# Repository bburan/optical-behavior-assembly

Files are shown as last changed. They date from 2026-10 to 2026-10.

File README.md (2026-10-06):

# Optical behavior assembly: parametric lickometer poke

A parametric [OpenSCAD](https://openscad.org/) model of a dual-beam, optical-fiber
lickometer poke, with presets for mice, rats and ferrets.

> **Status:** not yet print-tested. Fits, clearances and the optical signal across the
> wider rat/ferret beam gaps still need to be checked on a real print.

## Attribution

This work is **derived from the optical-fiber lickometer by Silva et al. (2024)**,
developed at the Champalimaud Foundation:

> Silva A, Carriço P, Fernandes AB, Saraiva T, Oliveira-Maia AJ, Alves da Silva J (2024).
> High-Precision Optical Fiber-Based Lickometer. *eNeuro* 11(7):ENEURO.0189-24.2024.
> https://doi.org/10.1523/ENEURO.0189-24.2024

Original design files: https://github.com/fchampalimaud/optical-lickometer (see
[`CONTRIB_ORIGINAL`](CONTRIB_ORIGINAL)). Their design includes the 3D-printed poke
(`Lickometer_Dual_Detection_Optical_Fiber-1..6`, LED and photosensor holders), laser-cut
acrylic panels, the electronics and Bonsai workflows. The hardware design files are
distributed under the [TAPR Open Hardware License v1.0](LICENSE); the article is published
under CC BY 4.0.

If you use this model, please cite the original article.

The core approach is theirs: a stack of 3D-printed plates that hold plastic optical
fibers in grooves, so that two beams cross the lick slot at two depths, clamped together
with screws and fed from a spout at the rear. This repository re-implements that approach
as a parametric model. It is not an official release of the original authors, and they
have not reviewed or endorsed it.

## Use of AI

The parametric model in this repository was developed with the help of an AI coding
assistant (Claude, by Anthropic), working from the original authors' STL files,
assembly instructions and design approach. The AI:

- measured the original STL meshes (cross-sections, plane and hole detection) and rebuilt
  the LED and photosensor holders as parametric OpenSCAD files;
- wrote the simplified, parametric redesign of the poke (`poke.scad`) and its presets;
- generated the STL exports and checked them (renders, part-overlap checks, clearance
  checks, overhang checks).

All design decisions and requirements were set and reviewed by the repository owner
([@bburan](https://github.com/bburan)). Treat the geometry as untested until it has been
printed and validated.

## Changes from the original design

As required by the TAPR OHL (section 4.2), these are the elements that were changed. The
modifications are licensed under the terms of the TAPR Open Hardware License v1.0.

- **New files:** everything in this repository is new documentation derived from the
  original poke and holder parts. The original files themselves are not modified.
- `led_holder.scad`, `photo_holder.scad`: parametric rebuilds of
  `Lickometer_Dual_Detection_Optical_Fiber_LED_Holder.STL` and `..._Photo_Holder.STL`
  (geometry within ~0.13 mm of the originals).
- `poke.scad`: a simplified, parametric redesign of poke parts 1–6:
  - PCB mounting features, the side fiber routing to the board-mounted LED/photosensor
    holders, the part 5 LED holder and the acrylic-panel boss were removed;
  - animal presets (mouse M/F, rat, ferret) set the beam gap and lick port size, and the
    body, fiber routing and fasteners are derived from them;
  - the fiber diameter and bend radius are parameters; the plates grow to fit them;
  - a fiber cover plate, printed locating posts, a 3D-printed spout with hose barb (rat,
    ferret) and a spout clamp plate were added;
  - the parts were adjusted for printing without support on a resin (SLA) printer.

## Files

| File | Contents |
|-|-|
| `lickometer_common.scad` | Shared helpers and fiber-holder base dimensions |
| `led_holder.scad` | Faithful rebuild of `..._LED_Holder.STL` |
| `photo_holder.scad` | Faithful rebuild of `..._Photo_Holder.STL` |
| `poke.scad` | Simplified parametric redesign of the poke (replaces parts 1–6) |
| `stl/<animal>/` | Pre-rendered poke parts in print orientation |
| `tools/` | Checks and measuring scripts: `check_all.py` re-exports every part and checks overlaps, stale STLs and printability; `meshtool.py`, `stl_diff.py`, `overhang.py` |
| `DESIGN_NOTES.md` | Measurements of the original design, parameter rationale, decisions and open items |
| `CLAUDE.md` | Working notes for AI-assisted editing (conventions, rules, commands) |

## Poke (`poke.scad`)

Choose the output with `part` (`assembly`, `exploded`, `bottom_block`, `fiber_plate_a`,
`fiber_plate_b`, `fiber_cover`, `top_block`, `friction_plate`, `spout`) and the animal with `animal`
(`mouse_M`, `mouse_F`, `rat`, `ferret`). The parameters appear in the OpenSCAD Customizer,
or you can set them on the command line:

    openscad -D 'part="top_block"' -D 'animal="ferret"' -o poke_top_block.stl poke.scad

The stack is described with the bottom block (blue in the assembly view) at the bottom and
the top block (green) at the top; the "front face" is the face the animal licks at and the
"rear" is the opposite face, where the fibers and spout leave.

Stack, bottom to top: bottom block → fiber plate A (deep beam, 5.75 mm) → fiber plate B
(shallow beam, 2.1 mm) → fiber cover → top block. Each fiber lies in the groove on the
top face of its plate, crosses the beam gap, and exits straight out of the rear (z = 0)
towards the remote electronics box. The fiber cover (`cover_t`, 1.2 mm; 0 = none) closes
plate B's groove right up to the beam gap, where the top block's wider lick port would
otherwise leave the fiber exposed. Trapezoidal wings on the plates and cover key into
recesses in the bottom block's ears (as in the original part 1), and two printed posts on
the bottom block pass through the plates and cover into the top block, so the fiber
guides are located during assembly.

### Animal presets

| Preset | Beam gap | Lick port (W × L) | Front | Spout | Body (W × L × D) |
|-|-|-|-|-|-|
| `mouse_M` | 3.3 mm | 6.0 × 12.1 mm | flat | 16G needle | 45.8 × 27.7 × 24 mm |
| `mouse_F` | 3.3 mm | 6.0 × 10.6 mm | flat | 16G needle | 45.8 × 27.7 × 24 mm |
| `rat` | 9.0 mm | 11 × 16 mm | flat | printed, Ø5.3 / bore 1.6 | 51.5 × 28.6 × 24 mm |
| `ferret` | 13.5 mm | 16 × 20 mm | flat | printed, Ø5.3 / bore 2.0 | 56.0 × 32.4 × 24 mm |

Body sizes are for the defaults (2 mm fiber, 10 mm bend radius).

The beam gap is the tongue width plus clearance (rat ~7.5 mm, ferret 8–12 mm). Presets
live in the `presets` table at the top of `poke.scad`. The body size, fiber routing,
clamp screw positions and screw length are derived from the beam gap and port size.
The acrylic-panel boss of the original can still be switched on per preset (second
column of the table) but is off for all presets.

### Fiber

The grooves are sized for a 2.0 mm fiber including jacket (`fiber_d`), with SLA
clearances: 2.3 mm wide (`fiber_clear_w`) and 2.15 mm deep (`fiber_clear_d`), so the
mating plate closes over the fiber without pinching it. The fiber plates are the groove
depth plus a fixed floor (`plate_a_floor` 1.35 mm, `plate_b_floor` 1.95 mm), i.e.
3.5 and 4.1 mm for a 2 mm fiber; the blocks, posts, clamp screws and spout follow.
The default bend radius (`fiber_bend_r`) is 10 mm; the original design used 4 mm.

`fiber_bend_r` is parametric: the fiber exit positions, body width and (above ~16 mm)
body depth grow to fit the bend, keeping a 3 mm straight run before each fiber tip
(`fiber_tip_straight`). The lick port depth is measured from the front face
(`port_depth`), so the spout stays within reach when the body gets deeper. The model
refuses to render if a groove comes closer than `groove_min_wall` to a clamp screw or
locating post. Approximate body size (W × D, mm):

| `fiber_bend_r` | mouse | rat | ferret |
|-|-|-|-|
| 4 | 39.6 × 24 | 41.0 × 24 | 46.0 × 24 |
| 10 (default) | 45.8 × 24 | 51.5 × 24 | 56.0 × 24 |
| 15 | 55.8 × 24 | 61.5 × 24 | 66.0 × 24 |
| 20 | 65.8 × 26.75 | 71.5 × 26.75 | 76.0 × 26.75 |
| 25 | 75.8 × 31.75 | 81.5 × 31.75 | 86.0 × 31.75 |

### Printed spout (rat, ferret)

The spout is a tube with a hose barb and a flange. The water tubing is set per preset
(last two columns of the `presets` table): ferret uses 3 mm (1/8") ID × 5 mm OD tubing
(barb 3.2–3.8 mm), and the clamp-plate hole lets the tubing slide over the whole barb up
to the flange. Rat is still set to 3.2 mm ID tubing with unknown OD.
It slides into a bore through the fiber plates from the rear, and the clamp plate
(`friction_plate`) holds the flange against the rear face. Print it standing on the barb
end: a 50° cone under the flange (`self_support_angle`) makes it print without support,
and the clamp plate has a matching conical seat. Use a material suitable for drinking
water (e.g. PETG or a biocompatible resin) and check that the bore is open and watertight
before use.

Both the spout and the friction / spout clamp plate print without support in their exported
orientation (no downward-facing surface steeper than 45° from vertical).

### Hardware

- 2× M3 socket head clamp screws (M3×22 mouse, M3×25 rat/ferret; printed in the console)
  + 2 square nuts in pockets in the top block's outer face (the pocket is deepened
  when needed so the screw reaches the nut)
- 4× M3×12 countersunk front mounting screws + 4 square nuts slid in from the outer faces
- 3× M3×12 button or socket head for the friction / spout clamp plate + 3 square nuts
  (plain holes; set `fc_countersunk = true` for countersunk screws, which adds 45°
  overhangs on the plate's bed side)
- mouse: 16G blunt needle as the spout (bore at the plate A / B interface)

Compared with the original, this version drops the PCB mounting features, the side
fiber routing to the LED/photo holders, the part 5 LED holder and the acrylic-panel boss.

The wider rat and ferret beam gaps reduce the light reaching the receiving fiber. Check
the receiver output (TP1/TP3, > 3 V recommended) with the fiber plates before printing
the rest. If it is too low, use thicker fiber (change `fiber_d`) or raise the receiver gain.

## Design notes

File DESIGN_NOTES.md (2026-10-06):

# Design notes

Knowledge behind `poke.scad`: what was measured on the original lickometer, why the
parametric model is shaped the way it is, what was decided and rejected, and what is
still open. Read this before changing the model. See [README.md](README.md) for usage and
[CLAUDE.md](CLAUDE.md) for the working rules and checks.

Original design: Silva et al. (2024), *eNeuro* 11(7):ENEURO.0189-24.2024,
https://github.com/fchampalimaud/optical-lickometer (TAPR OHL v1.0). Its files were
measured from the paper's supplementary material (`Hardware/CAD/*.STL`, assembly
instructions PDF, acrylic panel PDF, `Lickometer_model_v1.easm`).

## 1. How the original was reverse-engineered

- The STLs are binary meshes (no feature history). They were measured with
  `tools/meshtool.py`: axis-aligned planar faces (`planes`), cross-sections with circle
  fitting (`slice`), and section plots (`plot`). Rebuilds were validated with
  `tools/stl_diff.py` (volume and surface deviation).
- `Lickometer_model_v1.easm` (eDrawings) wraps a ZIP whose `eModel` is compressed HOOPS
  stream data (HSF). It was not decoded; the stacking order was derived from mating faces
  instead (section 2.2).
- The acrylic panel PDF has vector geometry; circle fits of its paths gave the panel holes.

## 2. Original design measurements

All dimensions in mm. "A frame" = the coordinate frame of the original part 1 STL:
X across (0..37.2), Y stacking direction (part 1 at y 0..15.7), Z depth (0 = rear,
24 = front face where the animal licks).

### 2.1 Original parts

| Part | Size (X × Y × Z) | Role |
|-|-|-|
| `-1` | 37.2 × 15.7 × 24 | rear block of the stack (our **bottom block**); body y 0–6.1, side "ears" x 0–5.44 and 31.76–37.2 extend to y 15.7 |
| `-2` | 31 × 3.9 × 24 | fiber plate with the deeper beam (our **plate A**); body 2.5 thick + a rib (x 14–17, z 0–9, 1.4 thick) |
| `-3` | 31 × 3.1 × 24 | fiber plate with the shallow beam (our **plate B**); base y 0.4–2.4, rim to 3.5; slot receives plate 2's rib |
| `-4_M` / `-4_F` | 37.2 × 12.8 × 24 | front block (our **top block**); M and F differ only in lick port length |
| `-5` | 13.2 × 7.9 × 24 | wedge in a V-notch of part 4 holding an LED (Ø4.5 bore, 0.5 mm pinhole at the front): cue light. Not reproduced. |
| `-6` | 20 × 21 × 4.5 | spout friction controller (our **friction_plate**) |
| LED holder | 6.5 × 28.1 × 6.25 | PCB-mounted fiber holder (rebuilt faithfully: `led_holder.scad`) |
| Photo holder | 6.5 × 28.1 × 6.25 | PCB-mounted fiber holder (`photo_holder.scad`); its STL sits at x = 17.8 (assembly position) |

### 2.2 Stack (A frame)

part 1 body y 0–6.1 → plate 2 y 6.1–8.6 → plate 3 y 8.6–11.7 → part 4 y 11.7–24.5.
(STL offsets: plate 2 +6.1; plate 3 and part 4 +8.2.) Part 1's ears cover the plates'
edges and reach 4 mm into a relief in part 4.

### 2.3 Key features (A frame)

- **Plate locating wings** (on plates 2 and 3, mirrored both sides): trapezoids sticking
  out 2.5 mm from the plate edge (plate edge at x 5.6 / 31.6), base z 5–14, flat tip
  z 7.75–11.25 (45° flanks), centred on z 9.5. Part 1's ears have the matching recess
  with ~0.15 clearance and filleted (~0.5) corners.
- **Beams:** plate 2 groove crosses the slot at z 18.25 (5.75 below the front), plate 3
  at z ~21.9 (2.1 below). Grooves ~1.1 wide × 1.1 deep on the plate faces; they run up
  the plate sides (x ~6.6–7.7) from z = 0 and bend inward with a ~3.5–4 mm radius.
- **Beam gap (lick slot in the plates):** 3.3 wide (x 16.95–20.25), from z 9 to the front.
- **Lick port in the blocks:** 6.0 wide at depth (7.5 at the front with a ~0.75 lead-in),
  stadium-shaped, y ~3.4 to ~15.5 (M) / ~14.0 (F): length ~12.1 (M) / ~10.6 (F).
  Port floor z = 9.
- **Spout:** 16G blunt needle (OD 1.65) in a Ø1.75 bore at (x 18.6, y 8.2), z 0–9.
- **Clamp screws:** 2 × M3×20 along Y at x 10.1 / 27.1, z 9.5; counterbore Ø~7 in part 1
  (~3.3 deep); nuts in part 4.
- **Front boss:** Ø~25 (R ~12.5, small top fillet), z 19–24, centre (18.6, 12.2), passes
  through the 5 mm acrylic panel. Panel hole Ø26.2.
- **Panel screws:** 4 × M3 countersunk at boss centre ± 14.75 (X) × ± 8 (Y) → (3.85 / 33.35,
  4.2 / 20.2), from the front face into square nuts.
- **Friction controller (part 6):** needle hole Ø1.9 at (10, 9.175) in its own frame;
  3 × M3 countersunk at (10, 4.275), (5, 16.775), (15, 16.775) = offsets (0, −4.9),
  (±5, +7.6) from the needle; O-ring pocket Ø5 × 1.2; two kidney-shaped flex slots.
  In the assembly the screws land in part 1 (x 18.6, y ~3.3) and part 4 (x 13.6/23.6).
- **Square nuts:** 11 × M3 square nuts (5 in part 1, 6 in part 4), in slots.
- **Male/female:** the only difference between parts 4_M and 4_F is the lick port length
  (and small related cavities near x 12–15 / 22–25, z ~12).

### 2.4 LED / photosensor holders (faithful rebuilds, within ~0.13 mm)

- Common body: stadium 6.5 × 28.1 × 6.25, 0.5 bottom chamfer, 2 × M3 holes Ø3.2 at
  y 3.25 / 24.85 with 0.5 chamfers both ends; fiber holes Ø1.25 with 0.2 bottom chamfer
  and a 45° countersink to Ø2.5 into the pocket.
- LED holder: 4 fibers at y 8.25 + 4n; pockets alternate 3.75 × 3.05 and 3.0 × 2.26,
  1.25 deep, with ~10° lead-in and 0.4 top fillet.
- Photo holder: 2 fibers at y 10.305 / 17.795 (pitch 7.49); pockets 4.25 × 5.35, 1.5 deep.

### 2.5 Original assembly facts (assembly instructions PDF)

- Fiber: 500 µm POF (Edmund 57-097), 4 pieces of ~77 mm, cut with a cutting block.
- Plates 1–4 clamped with 2 × M3×20 socket head; part 5 on 2 × M3×10 nylon spacers;
  poke to PCB with 4 × M3×12 nylon screws; holders to PCB with 4 × M3×12 nylon + nuts.
- Acrylic panels attached with 4 × M3×12 countersunk; part 6 with 3 × M3×12 countersunk
  plus a 1.6 mm ID silicone tube section / O-ring around the spout.
- Spout: 16G blunt needle (SAI 847.356.0321).
- Alignment check: > 3 V at the transimpedance amplifier outputs (TP3, TP1) with the beam
  unbroken.

## 3. The parametric model (`poke.scad`)

### 3.1 Structure

- One file; `part` selects what is rendered, `animal` selects a preset row.
- Every layer is `intersection(envelope, layer_region) − cutters`, so features cut across
  layers stay consistent automatically (e.g. a nut slot that crosses an interface leaves
  a matching relief in the neighbouring part).
- Stack along Y: bottom block → plate A → plate B → fiber cover → top block. Z = depth
  (0 = rear, `top_z` = front face). X across, centred on `x_c`.
- Derived quantities live in the `[Hidden]` section; tunables are in the Customizer
  sections above it. The console prints a one-line summary per render (body size, beam
  gap, bend radius, clamp screw length, spout/barb sizes).
- Asserts stop the render when a rule is violated (groove too close to a hole, no clamp
  screw length fits, port too close to an outer face, spout bore vs barb, seat too thin).

### 3.2 Presets and why

| Preset | Beam gap | Port W × L | Port bottom end* | Spout | Tubing |
|-|-|-|-|-|-|
| mouse_M | 3.3 | 6.0 × 12.1 | 5.5 | 16G needle | – |
| mouse_F | 3.3 | 6.0 × 10.6 | 5.5 | 16G needle | – |
| rat | 9.0 | 11 × 16 | 8.0 | printed, bore 1.6 | 3.2 ID, OD unknown |
| ferret | 13.5 | 16 × 20 | 10.0 | printed, bore 2.0 | 3 (1/8") ID × 5 OD |

\* from the plate-stack centre towards the bottom block.

- Beam gap = tongue **width** + clearance: mouse ~2–3 mm (original 3.3), rat ~7.5 mm → 9,
  ferret 8–12 mm → 13.5. Port width = gap + 2–2.5 mm so the fiber tips are recessed.
- Mouse values reproduce the original. The model has a regression guarantee for the
  mouse geometry at the original settings (see 3.6).

### 3.3 Parameter rationale (current defaults)

- **Fiber:** `fiber_d = 2.0` (2 mm OD incl. jacket, the fiber the user plans to use).
  Grooves `+0.3` wide (0.15/side) and `+0.15` deep for SLA (Form 4) tolerances, so the
  mating plate closes without pinching. The IF-C-E1000 (1 mm, 2.2 mm jacket) was
  considered and dropped (jacket too thick, discontinued).
- **Plate thickness = groove depth + floor** (`plate_a_floor` 1.35, `plate_b_floor` 1.95,
  the original's material behind the grooves). With 2 mm fiber: 3.5 and 4.1.
- **Bend radius** `fiber_bend_r = 10`. The fiber spec says ≥ 25 mm, but the original
  assemblers report the ~4 mm original radius works. Body width/depth grow with it
  (`fiber_x_off = max(clamp-derived, R + gap/2 + fiber_tip_straight)`,
  `depth = max(24, R + beam_a_depth + 1)`). Approximate W × D with 2 mm fiber:
  R4 39.6–46 × 24; R10 45.8–56 × 24; R15 55.8–66 × 24; R25 75.8–86 × 31.75.
- **Fiber exits at the rear** (z = 0). Side exits were proposed (no bend at all) and
  rejected: the fibers cannot exit the sides in the housing.
- **Beam depths** 5.75 / 2.1 below the front face (original). `port_depth = 15` is
  measured from the front face so the spout stays reachable when the body gets deeper.
- **Fiber cover** `cover_t = 1.2`: the top block's lick port is wider than the beam gap,
  which left plate B's groove (fiber tips) exposed. The cover has the plates' beam slot.
- **Locating:** ears + trapezoid wings (original approach, X and Z location of the plates
  while stacking) and two printed posts Ø2.5 on the bottom block (0.15 radial clearance,
  2 mm into the top block). Posts replaced 1.75 mm filament dowels because the plate halves
  (when split by a spout channel) were not connected to anything during assembly.
  `post_x_off` keeps ≥ 1 mm wall to the lick port.
- **Clamp screws:** chosen from `clamp_lengths` (incl. M3×18/22): the longest screw whose
  head seats 3.2 … (bottom_t − 1.5) deep; the nut pocket in the top block's outer face is
  deepened as needed but keeps ≥ 3 mm of top block in front of the plates. Currently
  mouse M3×22, rat/ferret M3×25.
- **Front mounting:** 4 × M3 at the corners (3.85 from the X sides, 4.2 / 4.3 from the
  Y faces; same pattern as the acrylic panel), nuts slid in from the outer Y faces. The
  acrylic boss (`panel_mount`) is off for all presets: no acrylic panel will be used.
- **Printed spout (rat, ferret):** OD 5.3 (`spout_od_nom`), in a round bore through the
  plates (≥ 0.8 mm plate wall each side) — or a full-thickness channel if the stack is
  too thin. Tip 1 mm above the port floor. Barb `tubing_id + 0.2 … + 0.8` (two cones),
  8 mm long. Flange Ø(OD + 3) × 1.5 with a 50° (`self_support_angle`) cone underneath so
  it prints without support; the clamp plate has a matching conical seat. When the tubing
  OD is known, the clamp-plate hole lets the tubing slide over the whole barb.
- **Friction / spout clamp plate:** screw offsets (0, −fc_bottom) and (±4.5, +7.6) from the
  spout; plain M3 holes for M3×12 button/socket heads (`fc_countersunk = false`, because
  countersinks are 45° overhangs on the bed side).
- **Clearances (SLA):** 0.15 per side for slides (ears, posts, spout), 0.2 for nuts and
  M3 holes (Ø3.4).
- **Colors** (assembly view): bottom block steel blue, plate A orange, plate B gold, cover
  tomato, top block green, clamp plate grey, spout light blue. Layers are `render()`ed in
  the assembly so the F5 preview does not let the last part cover the shared envelope.

### 3.4 Coordinates and naming

- "Bottom block" / "top block" (not back/front) — the user's preferred terms. "Front face"
  = where the animal licks (max Z); "rear" = where fibers and spout leave (Z = 0).
- `friction_plate` keeps its name (it is the spout clamp for rat/ferret).

### 3.5 Printing

- Printer: Formlabs Form 4, Tough 2000 V2 (user). Supports are placed manually in PreForm.
- Spout and friction plate print support-free in their exported orientation (checked);
  the spout still benefits from 3–4 touchpoints around the barb tip for stability.
  Tough 2000 is not rated for drinking water; consider a biocompatible resin for the spout.
  Flush the spout bore with IPA before curing.
- Keep support touchpoints off mating faces, grooves, posts and wings.

### 3.6 Verification approach

- `python tools/check_all.py` (see CLAUDE.md). Mouse regression: at `fiber_d = 1.0`,
  `fiber_bend_r = 4`, `cover_t = 0` the model reproduced the earlier committed mouse STLs
  vertex-for-vertex; refactors were checked this way at each step.
- Overlap checks render `intersection()` of two parts; "empty" or zero volume = OK. Use an
  absolute Windows path in the `include` (a POSIX `/c/...` path silently fails and makes
  every check look empty); `check_all.py` guards against this and includes a sanity case.

## 4. Open items

- First print: measure fits (ears/wings, posts, nut slots, grooves) and adjust
  `ear_clear`, `post_clear`, `fiber_clear_w/_d`, `nut_clear`.
- Optical signal across the 9 / 13.5 mm rat/ferret gaps (> 3 V at TP1/TP3); options if
  low: thicker fiber, lenses, more receiver gain.
- Rat water tubing size (preset still 3.2 ID, OD unknown).
- Cue LED (original part 5) not reproduced; could be added as a pocket in the top block.
- Spout material (biocompatible resin) and the effect of support nubs on the barb seal.
- TAPR OHL: email the modified documentation (repo link) to the addresses in
  `CONTRIB_ORIGINAL`.

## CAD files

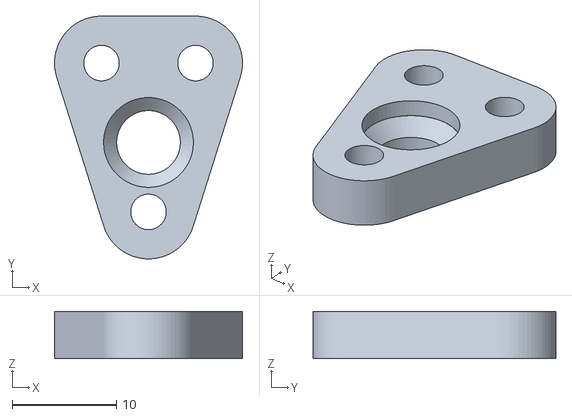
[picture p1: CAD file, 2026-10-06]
stl/ferret/poke_friction_plate.stl
18.0 x 23.2 x 4.50

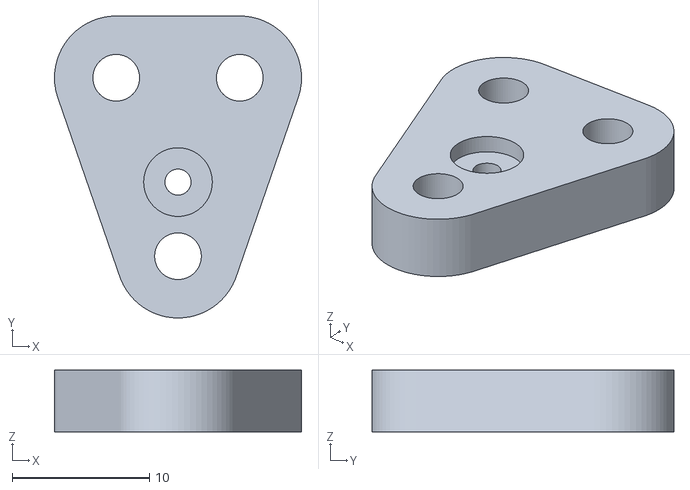
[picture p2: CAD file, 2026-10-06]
stl/mouse/poke_friction_plate.stl
18.0 x 22.0 x 4.50

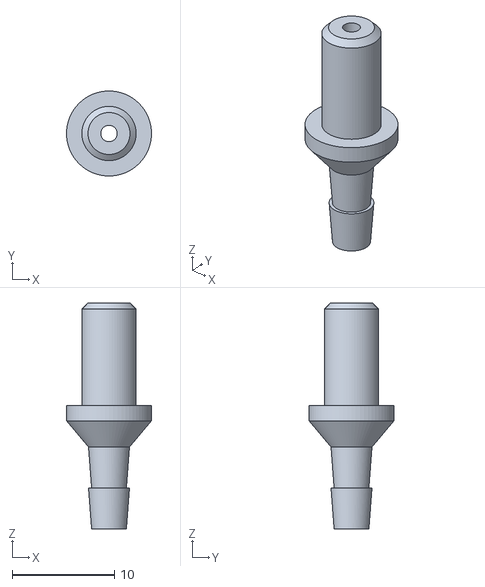
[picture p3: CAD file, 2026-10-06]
stl/rat/poke_spout.stl
8.30 x 8.30 x 22.1

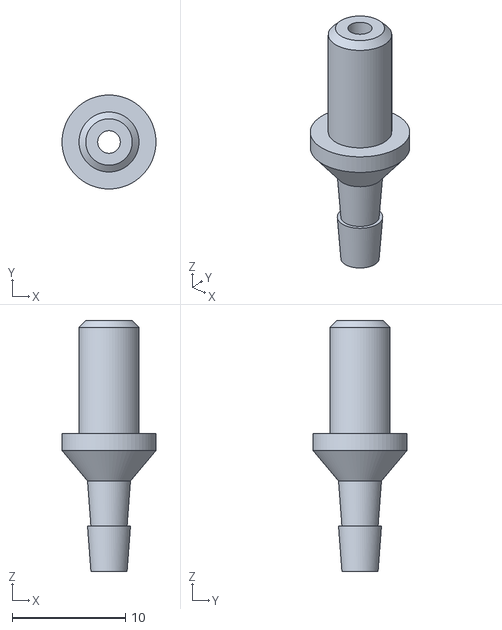
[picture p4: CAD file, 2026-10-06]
stl/ferret/poke_spout.stl
8.30 x 8.30 x 22.2

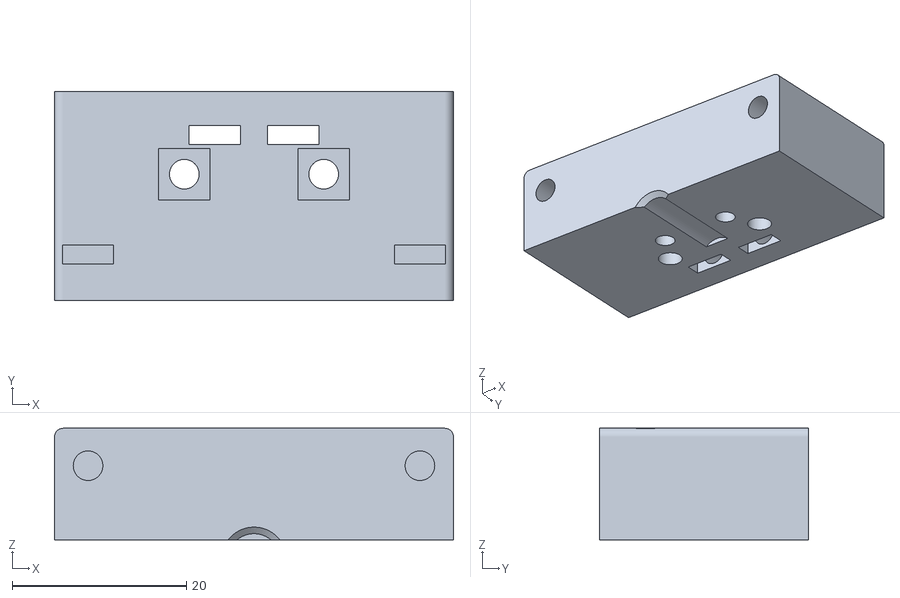
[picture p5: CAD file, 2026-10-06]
stl/mouse/poke_top_block_F.stl
45.8 x 24.0 x 12.8

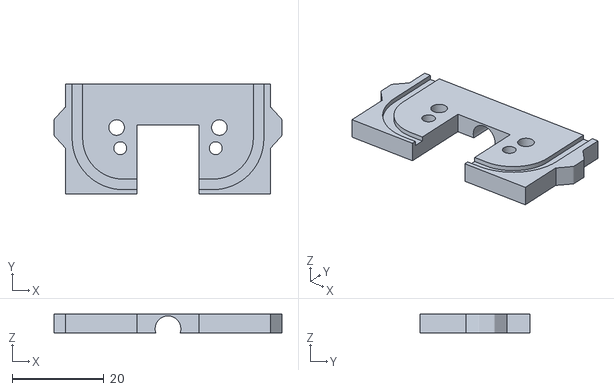
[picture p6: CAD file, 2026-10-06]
stl/ferret/poke_fiber_plate_b.stl
49.7 x 24.0 x 4.10

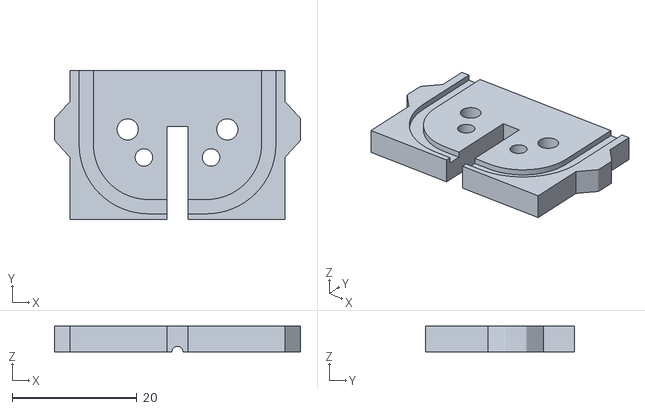
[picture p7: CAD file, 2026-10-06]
stl/mouse/poke_fiber_plate_b.stl
39.5 x 24.0 x 4.10

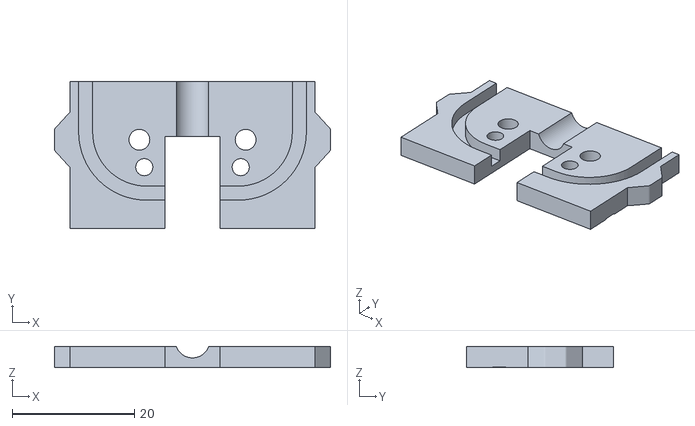
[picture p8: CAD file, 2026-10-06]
stl/rat/poke_fiber_plate_a.stl
45.2 x 24.0 x 3.50

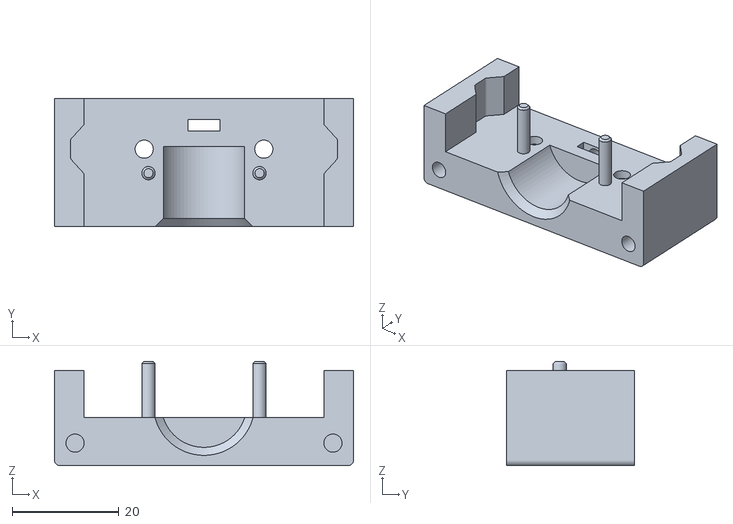
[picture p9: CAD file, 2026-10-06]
stl/ferret/poke_bottom_block.stl
56.0 x 24.0 x 19.5

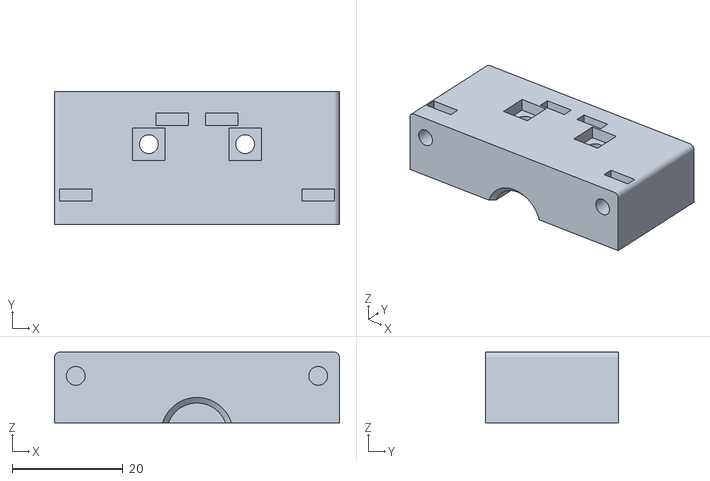
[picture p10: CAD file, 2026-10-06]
stl/rat/poke_top_block.stl
51.5 x 24.0 x 12.8

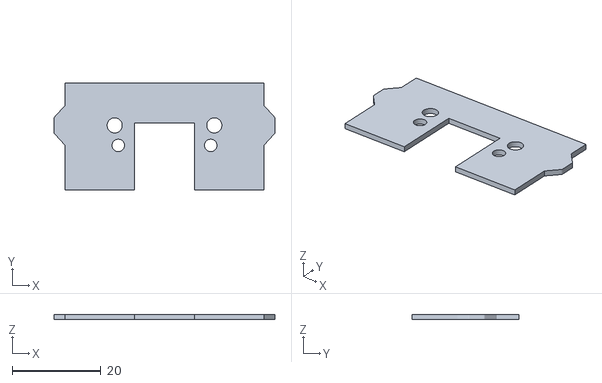
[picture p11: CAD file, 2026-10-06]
stl/ferret/poke_fiber_cover.stl
49.7 x 24.0 x 1.20

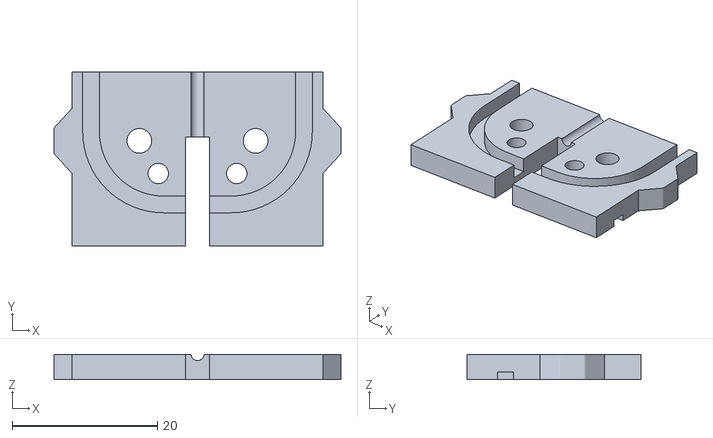
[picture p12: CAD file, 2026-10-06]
stl/mouse/poke_fiber_plate_a.stl
39.5 x 24.0 x 3.50

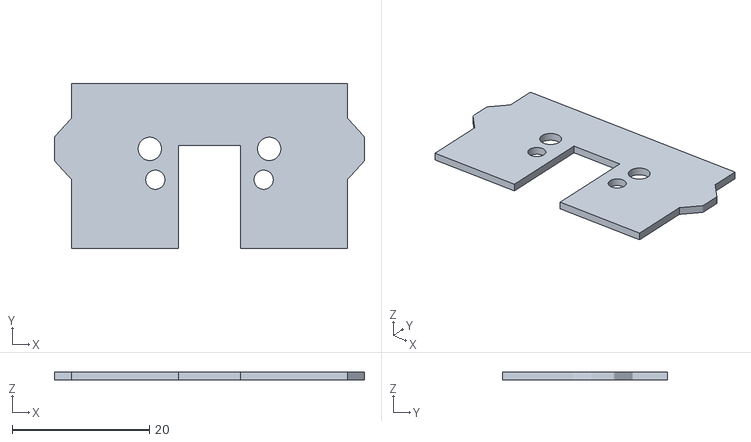
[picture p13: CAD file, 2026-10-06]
stl/rat/poke_fiber_cover.stl
45.2 x 24.0 x 1.20

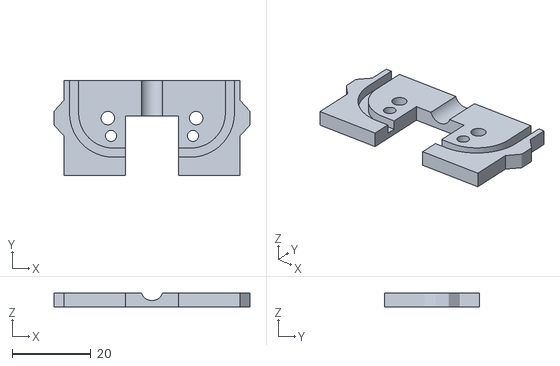
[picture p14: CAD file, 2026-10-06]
stl/ferret/poke_fiber_plate_a.stl
49.7 x 24.0 x 3.50

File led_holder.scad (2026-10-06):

// Lickometer_Dual_Detection_Optical_Fiber_LED_Holder
// Holds four optical fibers under four LEDs (two pocket sizes, alternating).
include <lickometer_common.scad>

fiber_y0       = 8.25;  // first fiber position along the bar
fiber_pitch    = 4.0;   // spacing between fibers
fiber_count    = 4;
pocket_depth   = 1.25;  // LED pocket depth from the top face
pocket_a       = [3.75, 3.05];  // pockets at even positions (1st, 3rd)
pocket_b       = [3.0, 2.26];   // pockets at odd positions (2nd, 4th)

module led_holder() {
    floor_z = fh_height - pocket_depth;
    difference() {
        fiber_holder_body();
        for (i = [0:fiber_count - 1]) {
            translate([fh_width/2, fiber_y0 + i*fiber_pitch, 0]) {
                fiber_hole(floor_z);
                translate([0, 0, floor_z])
                    pocket(i % 2 == 0 ? pocket_a : pocket_b, pocket_depth);
            }
        }
    }
}

led_holder();

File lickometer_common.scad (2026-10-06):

// Shared helpers for the lickometer 3D-printed parts.
// Reverse-engineered from the supplied STL files. All units are mm.

$fn = 64;
eps = 0.01;

// 2D stadium (slot) shape: width w across, total length l, ends fully rounded.
module stadium2d(w, l) {
    hull() {
        translate([w/2, w/2]) circle(d = w);
        translate([w/2, l - w/2]) circle(d = w);
    }
}

// Extruded 2D outline with a 45-degree chamfer of size c on the bottom edge only.
module bottom_chamfered_extrude(h, c) {
    hull() {
        linear_extrude(c + eps) offset(delta = -c) children();
        translate([0, 0, c]) linear_extrude(h - c) children();
    }
}

// Vertical through hole of diameter d, height h, with optional 45-degree
// chamfers c_bot / c_top at the bottom and top edges.
module chamfered_hole(d, h, c_bot = 0, c_top = 0) {
    translate([0, 0, -eps]) cylinder(d = d, h = h + 2*eps);
    if (c_bot > 0) translate([0, 0, -eps]) cylinder(d1 = d + 2*c_bot + 2*eps, d2 = d, h = c_bot + eps);
    if (c_top > 0) translate([0, 0, h - c_top]) cylinder(d1 = d, d2 = d + 2*c_top + 2*eps, h = c_top + eps);
}

// Rectangular pocket cutter, centred in XY, opening upwards from z = 0 to z = depth.
// Profile from the floor: vertical for `straight`, then a lead-in drafted at
// `draft` degrees, then a top-edge fillet of radius r.
module pocket(size, depth, straight = 0.25, draft = 10, r = 0.4, steps = 8) {
    function off(z) =
        let(zd = max(0, z - straight),                      // drafted part
            zf = z - (depth - r))                           // inside fillet zone
        zd * tan(draft) + (zf > 0 ? r - sqrt(r*r - zf*zf) : 0);
    zs = concat([0, straight],
                [for (i = [0:steps]) let(z = depth - r + r*i/steps) if (z > straight) z]);
    // stack hulls between consecutive levels so the flared (concave) profile is kept
    for (i = [0:len(zs) - 2])
        hull() for (z = [zs[i], zs[i+1]])
            translate([0, 0, z]) linear_extrude(eps)
                offset(delta = off(z)) square(size, center = true);
    translate([0, 0, depth - eps]) linear_extrude(1)
        offset(delta = off(depth)) square(size, center = true);
}

// Common body of the LED / photosensor fiber holders: stadium bar with two
// M3 clearance holes at its rounded ends.
fh_width        = 6.5;    // bar width (X)
fh_length       = 28.1;   // bar length (Y)
fh_height       = 6.25;   // bar thickness (Z)
fh_bottom_chamf = 0.5;    // 45-degree chamfer around the bottom edge
fh_mount_d      = 3.2;    // M3 clearance
fh_mount_chamf  = 0.5;    // chamfer on both ends of the mounting holes
fh_fiber_d      = 1.25;   // optical fiber hole
fh_fiber_chamf  = 0.2;    // chamfer at the fiber entry (bottom)
fh_fiber_csink_d = 2.5;   // 45-degree countersink diameter where the fiber exits into a pocket

module fiber_holder_body() {
    difference() {
        bottom_chamfered_extrude(fh_height, fh_bottom_chamf) stadium2d(fh_width, fh_length);
        for (y = [fh_width/2, fh_length - fh_width/2])
            translate([fh_width/2, y, 0])
                chamfered_hole(fh_mount_d, fh_height, fh_mount_chamf, fh_mount_chamf);
    }
}

// Fiber hole through the full bar height, countersunk into a pocket whose
// floor is at floor_z. Place at the hole centre.
module fiber_hole(floor_z) {
    chamfered_hole(fh_fiber_d, fh_height, c_bot = fh_fiber_chamf);
    csink = (fh_fiber_csink_d - fh_fiber_d)/2;
    translate([0, 0, floor_z - csink])
        cylinder(d1 = fh_fiber_d, d2 = fh_fiber_csink_d + 2*eps, h = csink + eps);
}

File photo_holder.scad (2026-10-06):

// Lickometer_Dual_Detection_Optical_Fiber_Photo_Holder
// Holds two optical fibers under two photosensors.
include <lickometer_common.scad>

fiber_y0     = 10.305;  // first fiber position along the bar
fiber_pitch  = 7.49;    // spacing between fibers
fiber_count  = 2;
pocket_depth = 1.5;     // photosensor pocket depth from the top face
pocket_size  = [4.25, 5.35];

module photo_holder() {
    difference() {
        fiber_holder_body();
        for (i = [0:fiber_count - 1])
            translate([fh_width/2, fiber_y0 + i*fiber_pitch, 0]) {
                fiber_hole(fh_height - pocket_depth);
                translate([0, 0, fh_height - pocket_depth]) pocket(pocket_size, pocket_depth);
            }
    }
}

photo_holder();

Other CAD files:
stl/rat/poke_friction_plate.stl
stl/mouse/poke_top_block_M.stl
stl/mouse/poke_fiber_cover.stl
stl/rat/poke_fiber_plate_b.stl
poke.scad
stl/ferret/poke_top_block.stl
stl/mouse/poke_bottom_block.stl
stl/rat/poke_bottom_block.stl

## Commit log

2026-10-06 Add parametric OpenSCAD lickometer parts
    - led_holder.scad / photo_holder.scad: rebuilds of the fiber holder STLs
    (within 0.13 mm of the originals), sharing lickometer_common.scad
    - poke.scad: simplified parametric redesign of poke parts 1-6 (fiber
    plate stack, M3 clamp/panel/friction-plate fasteners, M/F lick port),
    without PCB mounting features
    - stl/: poke parts exported in print orientation
    [led_holder.scad, lickometer_common.scad, photo_holder.scad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]
2026-10-06 Add locating wings between fiber plates and back-block ears
    Trapezoidal wings on the fiber plate edges key into matching recesses in
    the back block's ears (as in the original part 1), so the plates are
    located during assembly before the clamp screws go in.
    [poke.scad, poke_back_block.stl, poke_fiber_plate_a.stl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]
2026-10-06 Add rat and ferret presets, printed spout, and locating posts
    - Replace the sex switch with animal presets (mouse_M, mouse_F, rat,
    ferret); beam gap and lick port follow tongue width, and body size,
    fiber routing, clamp screw position and length are derived from them.
    Mouse geometry is unchanged apart from the locating posts.
    - Rat/ferret: flat front (no acrylic boss) and a 3D-printed spout with
    hose barb and flange, held by the clamp plate on the rear face.
    - Replace filament dowels with printed posts on the back block that the
    fiber plates (or plate halves) slide onto and that key into the front
    block.
    - Organize exported STLs per animal under stl/.
    [poke.scad, poke_back_block.stl, poke_fiber_plate_a.stl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]
2026-10-06 Parametric fiber size and bend radius; flat front for all presets
    - Fiber grooves sized for SLA (0.15 mm per side, 0.15 mm extra depth);
    default fiber is now 2.0 mm including jacket.
    - Fiber plate thickness follows the groove depth (fixed floor behind
    the groove), so the stack grows with the fiber; the printed spout
    keeps its OD and sits in a round bore when the plates allow it.
    - fiber_bend_r is parametric (default 10 mm): fiber exit positions,
    body width and depth grow to fit the bend, with a straight run before
    each fiber tip. Lick port depth is measured from the front face.
    Rendering stops if a groove gets too close to a clamp screw or post.
    - Mouse presets drop the acrylic b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
    [poke.scad, poke_back_block.stl, poke_fiber_plate_a.stl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]
2026-10-06 Size the ferret spout barb for 3 mm ID x 5 mm OD tubing
    Tubing ID/OD are now preset columns. The barb follows the tubing ID, and
    when the OD is known the clamp-plate hole lets the tubing slide over the
    whole barb up to the flange. Rat keeps its previous spout.
    [poke.scad, poke_friction_plate.stl, poke_spout.stl]
2026-10-06 Distinguish layers in the assembly view
    Give the front block its own color, drop the layer transparency, and
    render() each layer so the F5 preview draws the parts cut from the shared
    envelope instead of letting the last one cover the whole body.
    [poke.scad]
2026-10-06 Add fiber cover plate over plate B
    A 1.2 mm cover (cover_t, 0 = none) between fiber plate B and the front
    block closes plate B's groove up to the beam gap, so the fiber is not
    exposed in the front block's wider lick port. It has the plates' wings,
    post and clamp holes and spout bore, and the ears extend over it.
    The clamp nut pocket can now be deepened so a standard screw still
    reaches the nut in the longer stack (mouse stays M3x22).
    [poke.scad, poke_back_block.stl, poke_fiber_cover.stl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]
2026-10-06 Rename back/front block to bottom/top block
    Part names, STL file names, block-related parameters, comments and the
    README now use bottom block / top block. Geometry is unchanged.
    [poke.scad, poke_bottom_block.stl, poke_top_block.stl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]
2026-10-06 Make the spout and friction plate print without support
    - Spout: a self-supporting cone (self_support_angle, 50 deg) between the
    barb and the flange replaces the flat flange underside; the clamp
    plate gets a matching conical seat.
    - Friction / spout clamp plate: plain M3 holes for button or socket head
    screws by default (fc_countersunk = true restores the countersinks,
    which leave 45 deg overhangs on the bed side).
    - Re-exported spout and friction plate STLs.
    [poke.scad, poke_friction_plate.stl, poke_spout.stl]
2026-10-06 Add design notes, CLAUDE.md and check tools
    - DESIGN_NOTES.md: measurements of the original Silva et al. (2024)
    design, parameter rationale, decisions and rejected options, open
    items, so the model can be changed later without re-deriving them.
    - CLAUDE.md: conventions, rules for changes and commands for
    AI-assisted editing sessions.
    - tools/: check_all.py (re-export all parts; checks renders, stale STLs,
    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
